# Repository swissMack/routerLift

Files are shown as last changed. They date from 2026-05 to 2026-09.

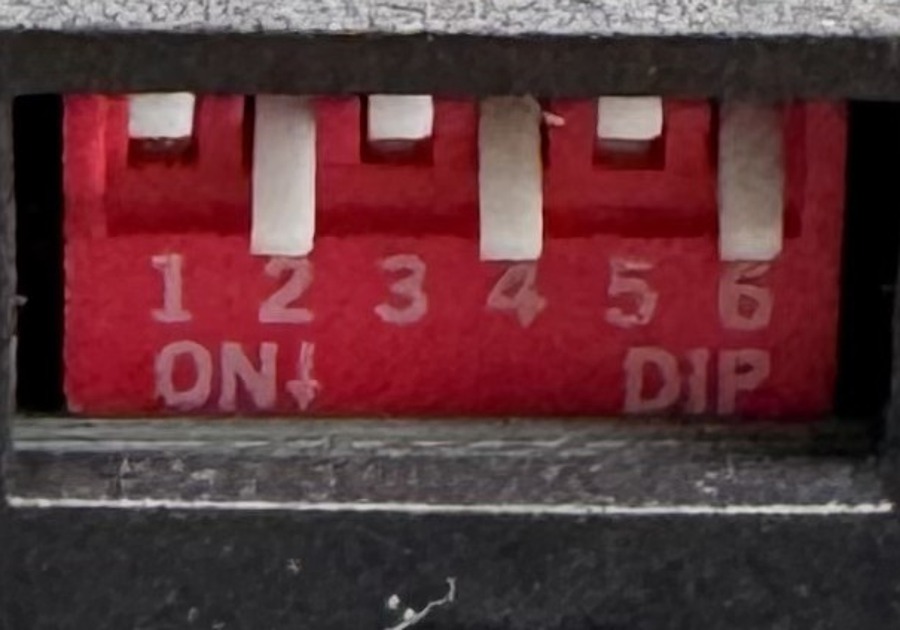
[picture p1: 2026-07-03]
docs/dip_zoom.jpg

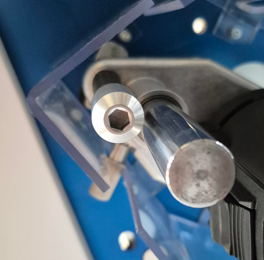
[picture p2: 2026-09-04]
docs/reference/sauter-fml-p-lower-hex.png

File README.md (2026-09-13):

# routerLift

Open-firmware automated router lift for a workshop router table. A 4.3" touch
panel with a CNC-style handwheel drives a stepper-actuated lift body, with
motion handled by stock [FluidNC](https://github.com/bdring/FluidNC).

Specification: `docs/Router_Lift_Requirement_Specification_RevG.md`, amended by
the Rev H design set.

## Architecture — two boards

Motion and the operator interface run on separate controllers. FluidNC does not
run on the ESP32-S3, and the S3 board cannot carry the machine's full pin
budget, so one board cannot do both.

```
  ESP32-S3 touch panel                 classic ESP32
  ┌──────────────────┐   UART/GRBL   ┌──────────────────┐
  │  hmi/  (our C++) │ ────────────► │ stock FluidNC    │   TB6600 ─► stepper
  │  LVGL, handwheel │ ◄──────────── │ firmware/*.yaml  │   NPN limits, probe
  └──────────────────┘  status @10Hz └──────────────────┘   relay ─► router
```

The HMI polls status with `?` every 100 ms — FluidNC's automatic report only
fires on change. No status for 500 ms counts as link loss: the HMI sends a feed
hold and invalidates Z0.

**The HMI has no motion authority.** Soft limits, hard limits, homing and
probing are all enforced by FluidNC. A bug in our firmware can produce a *wrong
cutting depth*; it must never produce an *unsafe move*. Keeping FluidNC stock
means the safety-critical parts are not ours to get wrong — any proposal that
needs FluidNC source edits forfeits that.

| Directory | Contents |
| --- | --- |
| `firmware/` | FluidNC machine definition — `config.yaml` only, **no source** |
| `hmi/` | PlatformIO ESP32-S3 project: LVGL UI, handwheel, buttons, GRBL sender |
| `legacy/` | The retired v1.x single-ESP32 firmware. Reference only, not built |
| `docs/` | Spec, Rev H design set, wiring, protocol, bench tests, mechanics |

## Hardware

**Motion board** — classic ESP32 (30-pin USB-C ESP32-WROOM-32 devkit) running
unmodified FluidNC v4.1.0. TB6600 driver at 1/8 microstepping (1600 pulse/rev),
24–36 V, common anode +3.3 V, 1.0–1.4 A/phase. NPN NC inductive limit switches,
`G38.2` probe for tool zeroing, `Relay` spindle output for router power with a
2500 ms spin-up gate. Host lift: sauter FML-P (1.5 mm lead, 65 mm travel).

**Operator panel** — Guition JC4827W543C board (XH-S3E N4R8 module: ESP32-S3,
4 MB flash, 8 MB octal PSRAM). 4.3" 480×272 IPS NV3041A panel over QSPI via
Arduino_GFX, GT911 capacitive touch, LVGL 8.4. The board brings only ten GPIOs
out to connectors, so the panel buttons and the rough/fine selector sit on an
MCP23017 on its own I²C bus (GPIO 15/16) — the touch bus is not brought out.
MPG handwheel decoded on the S3's PCNT peripheral (GPIO 6/7), through a 74LVC14
on 3.3 V (two stages per channel, non-inverting).

STOP is deliberately *not* on the panel: it is wired to FluidNC's own
`feed_hold_pin`, so it halts motion even if the HMI has crashed.

Full pin map and wiring: `docs/HARDWARE.md`, `docs/WIRING-RevH.svg`,
`docs/SCHEMATIC-RevH.svg`, `docs/PINOUT.svg`.

## Status

Bench truth lives in `docs/BRINGUP-LOG.md`. As of 2026-09-13:

| Half | State |
| --- | --- |
| Motion board | ✅ FluidNC v4.1.0 flashed, `config.yaml` parses, bare-board acceptance passed (limits NC-correct). Five items still to verify — `firmware/README.md` |
| Screen board | ✅ Display and touch working on the JC4827W543C |
| UART link (Step B) | ✅ Link up, link-loss feed hold + Z0 invalidation, recovery verified |
| `hmi/` increments 1–3 | Built. Display, touch and link bench-verified; MPG and buttons **not yet wired** (waiting on the level shifters) |
| `hmi/` increment 4 | Cycles (standard → bit-change → dovetail → keyhole). Not started |
| `hmi/` increment 5 | Fault log, diagnostics, runtime hours. Not started |
| Mechanics | Lift body (sauter FML-P) **not yet bought**. See `docs/MECHANICS-RevH.md` |

HMI flash use is ~24% of the 3 MB app slot.

### Nothing has been cut yet

Two numbers come from the sauter FML-P datasheet, not a measurement, and both
follow from its 1.5 mm screw lead:

- `firmware/config.yaml` → `steps_per_mm: 1066.67` (1600 pulse/rev ÷ 1.5 mm),
  with `max_travel_mm: 65`
- `hmi/include/config.h` → `MpgCfg::SCREW_LEAD_MM = 1.5`

**Until `steps_per_mm` is measured against a dial indicator, every depth this
machine cuts is wrong by an unknown factor** — and wrong invisibly, because
there is no stall detection to contradict a bad number. The commissioning
procedure is in `firmware/README.md`.

One design question is also open: the foot switch needs both press and release
edges for dead-man behaviour, and FluidNC's `macro0_pin` may only fire on
assert. The proposed split (press on FluidNC, release mirrored to an HMI
expander input) is written up in `firmware/README.md` and not yet verified.

## Build

Only the HMI is built from this repo. FluidNC is flashed from its own release.

```sh
git clone git@github.com:swissMack/routerLift.git
cd routerLift
pio run -e hmi           # compile
pio run -e hmi -t upload # flash the S3 panel
pio run -e hmi-diag      # bring-up diagnostics build (no I2C, display logging)
pio device monitor       # serial console at 115200
```

Libraries resolve on first build: ESP32Encoder, GFX Library for Arduino, LVGL
8.4, TAMC_GT911. If upload cannot connect because the app has hung, hold BOOT,
tap RST and retry.

For the motion board, flash stock FluidNC from installer.fluidnc.com, upload
`firmware/config.yaml` with `$Xmodem/Receive=/localfs/config.yaml`, and restart
with `$Bye` — see `firmware/README.md`. Its console is also reachable over WiFi:
`telnet routerlift.local 23`.

## Documentation

| File | Contents |
| --- | --- |
| [docs/Router_Lift_Requirement_Specification_RevG.md](docs/Router_Lift_Requirement_Specification_RevG.md) | The requirement spec |
| [docs/DESIGN-PLAN-RevH.md](docs/DESIGN-PLAN-RevH.md) | The RevG pivot, phase by phase |
| [docs/UART-PROTOCOL.md](docs/UART-PROTOCOL.md) | HMI ↔ FluidNC command vocabulary |
| [docs/MECHANICS-RevH.md](docs/MECHANICS-RevH.md) | Lift body selection and stepper drive design |
| [docs/LIFT-COMPARISON.md](docs/LIFT-COMPARISON.md) | The four candidate lift bodies, compared |
| [docs/BOM.md](docs/BOM.md) | Bill of materials |
| [docs/HARDWARE.md](docs/HARDWARE.md) | Pin map and wiring detail |
| [docs/BENCH-TEST.md](docs/BENCH-TEST.md) | Staged bring-up — each step passes before the next part is fitted |
| [docs/BRINGUP-LOG.md](docs/BRINGUP-LOG.md) | What has actually been proven on the bench, session by session |
| [docs/UX.md](docs/UX.md) | Interaction model |
| [docs/DESIGN-QA.md](docs/DESIGN-QA.md) | The design Q&A that settled the constants |
| [hmi/README.md](hmi/README.md) | HMI modules, build gotchas, Z0 validity rules |
| [firmware/README.md](firmware/README.md) | FluidNC setup, pre-power-up checks, commissioning |
| [CHANGELOG.md](CHANGELOG.md) | Version history |
| [CONTRIBUTING.md](CONTRIBUTING.md) | Code style, commit conventions |

`docs/SUPERSEDED.md` lists the drawings the Rev H set replaced.
`docs/reference/FXBB-original/` holds the FXBB FräsLift V3 documentation this
project draws on.

## Safety

This machine drives a high-RPM router. Read `firmware/README.md` before first
power-up — five of its checks are destructive or silently wrong if got wrong,
including PSU voltage (48 V destroys the TB6600), TB6600 common anode at 3.3 V
not 5 V, and NPN-not-PNP limit sensors.

Z0 — the reference every cut depth is measured from — is owned entirely by the
HMI, and **there is no override anywhere** on probe validity. That is
deliberate: a wrong reference does not fail visibly, it produces a
plausible-looking cut at the wrong depth. See `hmi/README.md`.

The author accepts no liability for misuse. Test with the router unpowered
first.

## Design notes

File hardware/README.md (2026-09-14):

# Hardware — KiCad schematics (Rev H)

Generated from Python. **Do not edit the `.kicad_sch` files in KiCad** — the next
regeneration overwrites them. Change `tools/*.py` and run:

    hardware/tools/verify.sh     # tests, generate, ERC, PDFs, pin cross-check

After running `verify.sh`, restore unchanged PDFs with `git checkout -- hardware/*/*.pdf` unless the schematics actually changed.

| Project | What | For layout? |
| --- | --- | --- |
| `motion-carrier/` | ESP32 devkit sockets, 5 input conditioners, field terminals, link header | Yes |
| `panel-carrier/` | 74LVC14 MPG shifter, MCP23017 + pull-ups, MX1.25 leads to the display | Yes |
| `system/` | Mains, E-stop, PSU, modules and cabling between them | No — reference |

`tools/check_pins.py` fails if a schematic pin disagrees with `firmware/config.yaml` or
`hmi/include/pins.h`.

## PCBs

Boards are generated once, then **the routed `.kicad_pcb` is the source** — edit it in KiCad's PCB
Editor freely. Rebuilding from scratch overwrites hand edits:

    hardware/tools/get_freerouting.sh                                   # once
    /Applications/KiCad/KiCad.app/Contents/Frameworks/Python.framework/Versions/Current/bin/python3 \
      hardware/tools/gen_pcb.py motion-carrier                          # or panel-carrier

`get_freerouting.sh` fetches v2.1.0, which runs on Java 21. `gen_pcb.py` uses only the jar for
that pinned version (`hardware/tools/.cache/freerouting-2.1.0.jar`) and stops with an error if it
is missing. To try another version, delete the cached jar first, then run e.g.
`FREEROUTING_VERSION=v2.4.1 hardware/tools/get_freerouting.sh` — and run `gen_pcb.py` with the same
`FREEROUTING_VERSION` set. v2.2 and later need Java 25.

**Regenerating a board is destructive.** It overwrites the `.kicad_pcb`, replaces the `board` and
`net_settings` sections of its `.kicad_pro` (design rules and net classes edited in the GUI are
discarded; other sections are kept), and rewrites the fab zip, the board PDF and the renders.

`verify.sh` and `gen_pcb.py` run DRC with schematic parity and `--severity-all`, so warnings fail
too. Autorouting gives a different result each run, so check DRC after every regeneration.
Fabrication zips for JLCPCB (2-layer, 1.6 mm, HASL) are in `<board>/fab/<board>-jlcpcb.zip`.

| Board | Size | Mounting |
| --- | --- | --- |
| motion carrier | 140 × 80 mm | 4× M3 for standard DIN-rail PCB clips |
| panel carrier | 80 × 62 mm | 4× M3 corners, standoffs |

Mounting hole centres, in mm from the board's top-left corner (x right, y down). Each board's holes
form a rectangle:

| Board | Holes (x, y) | Pitch (x × y) |
| --- | --- | --- |
| motion carrier | (4, 4), (93, 4), (4, 56.5), (93, 56.5) | 89 × 52.5 mm |
| panel carrier | (4, 4), (76, 4), (4, 58), (76, 58) | 72 × 54 mm |

## Open items shown on the drawings

- Contactor coil voltage (BOM block A).
- MPG output type — R3/R4 on the panel carrier are DNP until known.
- Foot-switch release mirror (MCP GPA6) — needs a second pedal contact or a shared-contact decision.
- ESP32 devkit row spacing assumed 25.4 mm — measure before ordering boards.
- DIN-rail clip hole spacing — check against the clips bought.

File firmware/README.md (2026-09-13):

# Motion controller — stock FluidNC

This directory contains **no source code**. The motion controller runs an unmodified FluidNC
binary; `config.yaml` is the entire machine definition.

That is deliberate and worth protecting. Homing, soft limits, hard limits, probing and step
generation are the safety-critical parts of this machine, and keeping FluidNC stock means they
are not ours to get wrong. Any proposal that requires editing FluidNC's source forfeits this.

---

## Flashing and configuration

1. Flash stock FluidNC to the ESP32 (**classic ESP32, not S3** — FluidNC does not run on the S3).
   Easiest: **installer.fluidnc.com** in Chrome or Edge (Web Serial), WiFi build.
2. Upload `config.yaml` to the board's filesystem — from the installer's file browser / terminal
   (`$Xmodem/Receive=/localfs/config.yaml`, confirm the `Received N bytes` count matches the local
   file), or via the FluidNC web UI — `routerlift.local` once it has joined WiFi, or
   `192.168.0.1` on the `FluidNC` fallback access point.
3. `$Config/Filename=config.yaml` if it is not the default.
4. **Restart with `$Bye`** — `$CD` shows the config loaded at the last boot, not the file on disk.
5. Read the boot log from the first line. Any `[MSG:ERR:` line, or `Board None` with a
   1000 mm Z axis, means the YAML did not parse and FluidNC fell back to defaults — the safe
   non-configured state. `$CD` dumps what was actually loaded.

**YAML parser gotchas (FluidNC v4.1.0):**
- The spindle section key is `Relay:` — `relay_spindle:` is silently ignored.
- Never put a comment on a section-header line, and never use `'` or `"` inside comments. An
  apostrophe in a comment on `Relay:` broke parsing of the whole file.

Flashed: **FluidNC v4.1.0 (esp32-wifi)**, 2026-09-13, on a 30-pin USB-C ESP32-WROOM-32 devkit
(CH340, 4 MB flash).

### Bare-board acceptance (passed 2026-09-13)

Board on USB only, nothing else connected:

| Check | Expected |
| --- | --- |
| Boot log | `Machine routerLift`, `Board ESP32 devkit v1`, no `ERR` lines |
| Z axis | `Axis Z (-0.001,65.001)`, `stepstick Step:gpio.26 Dir:gpio.27 Disable:gpio.14` |
| Relay | `Relay Spindle Ena:NO_PIN Out:gpio.4` |
| HMI link | `UART1 Tx:gpio.17 Rx:gpio.16 … Baud:115200`, report interval 100 |
| Limits, unwired | `ALARM: Hard Limit` and `Pn:Z` — correct, NC wiring reads open as tripped |
| Limits, D33 + D25 jumpered to GND | `?` shows no `Pn:Z`; after `$Bye` only `ALARM:14` (Unhomed, from `must_home`) |

`E (…) esp_core_dump_flash: No core dump partition found!` appears on every boot. It is harmless
— FluidNC's partition table has no core-dump area.

### Console and network

- **WiFi:** joins the home network as `routerlift.local` (192.168.1.82 on the bench); if it
  cannot, it falls back to access point `FluidNC` with the default password `12345678` — change
  it before commissioning, or `$WiFi/Mode=Off`.
- **Telnet console, port 23:** `telnet routerlift.local 23` gives the same `?`, `$` commands and
  messages as the USB serial port. Use it when USB serial does not enumerate (e.g. a charge-only
  cable), or while the HMI is on UART1.
- **`$Limits`** shows the live state of every input pin, per pin. Exit with **`!`** — any other
  key leaves it running. A limit that reads active with the switch closed is usually a bad
  jumper or terminal, not the GPIO.

---

## ⚠ Before first power-up

Five things that are destructive or silently wrong if got wrong. All are in
`docs/WIRING-RevH.svg` too.

| # | Check |
| --- | --- |
| 1 | **PSU is 24–36 V.** A 48 V supply destroys the TB6600 instantly (abs max ≈40–42 V) |
| 2 | **TB6600 common anode is +3.3 V, not +5 V.** At 5 V the input opto never fully turns off → missed steps at rapid → silent depth error under DEV-01 |
| 3 | **Limit sensors are NPN, never PNP.** A PNP sensor sources 24 V into the GPIO. `LJ12A3-4-Z/BY` = NPN NC; any `/A…` suffix is PNP |
| 4 | **Switches wired NC**, so a broken wire faults the machine rather than silently disabling the limit |
| 5 | **Two red buttons, two meanings.** The E-stop mushroom kills mains; STOP is a flush feed-hold button. Mount them apart |

---

## ⚠ Unresolved: the foot switch needs both edges

**This is the one genuine problem found while writing the config, and it is not yet solved.**

The agreed behaviour (Q39) is **hold to plunge, release to retract** — dead-man, so stepping off
returns the cutter. That needs two events: press *and* release.

FluidNC's `macro0_pin` fires a macro when the pin is **asserted**. Whether it does anything on
release is unverified, and if it does not, a macro pin alone cannot implement dead-man behaviour.

There is a second problem even for the press half. A macro is a fixed G-code string, but the
plunge target is a per-job value that lives in the HMI. FluidNC cannot know it.

### The plan, pending verification

**Press half.** The HMI rewrites the macro whenever the target depth changes:

```
$Macro0=G90 G21 G1 Z<target> F120
```

The foot switch then plunges **locally on the motion board**, with no link involvement and no
latency — which is exactly why the switch belongs on this board.

**Release half.** Wire the same foot-switch contact to a **spare MCP23017 input on the HMI**
(A6 — ten I/O are free). The HMI sees the release edge and sends the park move. One switch, two
readers, no ambiguity about which owns the plunge.

### Consequences to accept or reject at review

- If the link is dead, the plunge still works but the automatic retract does not. Link loss
  already triggers a feed hold, so the cutter stops — but it stops **at depth**, not retracted.
- That is weaker dead-man behaviour than a single-board design gives. It is a direct cost of the
  split architecture and should be judged deliberately, not discovered on the bench.

### Alternatives if verification rules the mirrored approach out

1. Move the foot switch entirely to the HMI expander — both edges are then trivial, but every
   plunge crosses the link and gains latency.
2. Change the semantics to press-down / press-up toggle — solvable with one edge, but it is a
   mode, and losing track of it means the cutter stays up when you think it is down. Q39
   deliberately rejected this.

---

## Items to verify against the installed release

Everything in `config.yaml` marked ⚠, plus these. All are from working knowledge of FluidNC
rather than from the docs of the specific build in hand.

| # | Item | Why it matters |
| --- | --- | --- |
| 1 | ✅ `uart1:` / `uart_channel1:` key names — **verified v4.1.0** | Without a second channel the HMI shares the USB port and the debug console is lost |
| 2 | ✅ `report_interval_ms` exists — **verified v4.1.0**, but it only reports **on change**, not as a heartbeat. Resolved: the HMI polls `?` every 100 ms and treats 500 ms of silence as link loss (Step B, 2026-09-13) | An idle machine in Alarm sends nothing, so without polling the HMI shows NO LINK |
| 3 | Soft-limit envelope sign convention | We home negative and work positive — the less common orientation. Prove with `$J=` at both ends |
| 4 | `macro0_pin` edge behaviour | Decides the foot-switch question above |
| 5 | Macro length limits, and whether `$Macro0` can be rewritten over the wire | The press-half plan depends on it |
| 6 | Homing pull-off failure raises a distinct alarm code | So the HMI can say "stuck switch", not just "limit" |
| 7 | `Relay:` spindle reports non-zero `S` in status (the section key is `Relay:`, verified v4.1.0) | The ROUTER LED depends on reading it |

---

## Commissioning: measuring `steps_per_mm`

**`steps_per_mm: 1066.67` in `config.yaml` is derived, not measured.** It comes from the sauter
FML-P's published 1.5 mm lead and the TB6600 at 1600 pulse/rev (1600 / 1.5). Confirm it on the
real lift before trusting any depth.

1. Fit a dial indicator (0.01 mm) against the carriage.
2. `$J=G91 G21 Z10 F300` and note indicated travel — or command a known number of motor
   revolutions, which is more precise.
3. `steps_per_mm = 1600 / (mm travelled per motor revolution)`
4. Update `config.yaml`, re-upload, and repeat to confirm.
5. Record the measured value and date here: `__________`

Until this is done, every depth this machine cuts is wrong by an unknown factor — and wrong in a
way nothing detects, because DEV-01 leaves no stall sensing to contradict a bad number.

---

## Settled values and where they came from

| Setting | Value | Decided in |
| --- | --- | --- |
| `steps_per_mm` | **1066.67 — derived from FML-P spec, not yet measured** | `docs/MECHANICS-RevH.md` |
| `max_rate_mm_per_min` | 720 (12 mm/s) | Q14 |
| `acceleration_mm_per_sec2` | 100 | Q16 |
| `max_travel_mm` | 65 — FML-P published travel, not yet measured | MEC-01 |
| Lead / microstepping → steps | 1.5 mm lead, 1600 pulse/rev → 1066.67 steps/mm | `docs/MECHANICS-RevH.md` |
| TB6600 current | 1.0–1.4 A/phase, common anode +3.3 V | `docs/BOM.md` |
| `idle_ms` | 255, never disable | Q17 |
| Homing seek / feed | 600 / 60 mm/min | Q14–16 |
| `pulloff_mm` | 2.0 mechanical, ~3.0 inductive | Q12 |
| Positive direction | Bit rising, home at bottom | Q19 |
| Microstepping | 1/8, 1600 pulse/rev | Q18 |
| `spinup_ms` | 2500 | SAF-03 gate |
| `must_home` | true, no exceptions | Q11 |

Plunge feed (2 mm/s, 120 mm/min) is not in this file — it is a `G1 F` value the HMI sends per
move, since it varies by cycle.

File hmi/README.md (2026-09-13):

# HMI — ESP32-S3 operator panel

Our firmware. Runs on the Guition JC4827W543C (XH-S3E N4R8 module: ESP32-S3, 4 MB flash, 8 MB
octal PSRAM) and acts as a **GRBL sender** to the FluidNC board over UART.

```sh
pio run -e hmi          # build
pio run -e hmi -t upload
pio run -e hmi-diag     # board bring-up diagnostics
pio device monitor
```

Upload goes over the S3's native USB (`/dev/cu.usbmodem*`) and auto-resets. Only if the app has
hung: hold **BOOT**, tap **RST**, then upload.

`hmi-diag` skips all I²C (touch and MCP23017), waits for USB, logs display bring-up and cycles
red/green/blue. Never leave it on a panel in service — it has no touch or buttons.

## Pins (all in `include/pins.h`)

| Function | GPIO | Connector |
| --- | --- | --- |
| UART to FluidNC | TX 18 → FluidNC 16, RX 17 ← FluidNC 17 | P4 (P5 is the same — use one) |
| MPG A / B | 6 / 7, via a **74LVC14 on 3.3 V**, two stages per channel | P3 |
| MCP23017 (I²C bus 1, 100 kHz) | SDA 15 / SCL 16, external 4.7 kΩ pull-ups to 3.3 V | P3 |
| GT911 touch (I²C bus 0, on-board only) | SDA 8 / SCL 4, INT 3, RST 38 | — |
| NV3041A QSPI panel | CS 45, SCK 47, D0–D3 21/48/40/39, backlight 1 | — |
| Spares | 5, 9, 14 — **avoid 46** (boot strap) | P2 |

The MPG shifter is non-inverting, so `MpgCfg::SIGNALS_INVERTED = false`. A 74HCT14 is the wrong
part: it needs a 5 V supply and would drive 5 V into the S3.

## Restoring the factory demo

The board's original firmware is backed up in full (4 MB) at
`~/Documents/routerLift-firmware-backups/screen-original-dashboard.bin`. Restore with:

```sh
esptool.py --chip esp32s3 write_flash 0 screen-original-dashboard.bin
```

## Architecture invariant

**This board has no motion authority (ELE-11).** Soft limits, hard limits, homing and probing are
enforced by FluidNC. Nothing here may enforce a limit or be the last line of defence. A bug in
this firmware can produce a *wrong cutting depth*; it must never produce an *unsafe move*.

`Link` is the single chokepoint — nothing else may write to the UART. That is what keeps the
command vocabulary in `docs/UART-PROTOCOL.md` §4 exhaustive rather than aspirational.

**Status polling.** `Link` sends the `?` realtime byte every 100 ms (`LinkCfg::POLL_MS`).
FluidNC's `report_interval_ms` only reports on change, so without polling an idle machine sends
nothing and the link reads as lost. No status for 500 ms (`LinkCfg::TIMEOUT_MS`) = link lost:
feed hold is sent and Z0 is invalidated. Z0 stays invalid after the link recovers.

## Increments

| # | Scope | State |
| --- | --- | --- |
| 1 | Link, handwheel, buttons, headless serial diagnostics | Built. Link ✅ bench-verified (Step B); handwheel and buttons **not yet wired** |
| 2 | Display: Arduino_GFX NV3041A QSPI panel + GT911 touch + LVGL + main screen | Built. ✅ Display and touch bench-verified |
| 3 | Z0 validity, two-touch probe sequencing, named presets in NVS | Built. Z0 invalidation on link loss ✅ verified; probe not yet tested |
| 4 | Cycles: standard → bit-change → dovetail → keyhole | Not started |
| 5 | Fault log, diagnostics screen, runtime hours | Not started |

Increment 3 is enough, once the MPG, buttons and probe are wired, to attempt bench-test steps 1,
2, 4, 5 and the probe half of 7: the panel renders and touch tracks, the link comes up and status
is parsed, one detent moves the axis exactly 0.01 / 0.10 mm, the buttons and rough/fine selector
read correctly, and a two-touch probe sets Z0 while a failed probe leaves it invalid. Bench
progress is logged in `docs/BRINGUP-LOG.md`.

Flash ~24% of the 3 MB app slot (`huge_app.csv`).

## Modules

| File | Responsibility |
| --- | --- |
| `Link.{h,cpp}` | GRBL sender. Status parsing, one-command-in-flight window, realtime bytes |
| `Wheel.{h,cpp}` | MPG decode via PCNT, coalescing, look-ahead clamp, cancel-on-reversal |
| `Buttons.{h,cpp}` | MCP23017 polling, debounce, short/long press, ROUTER LED |
| `Display.{h,cpp}` | NV3041A QSPI panel, GT911 touch, LVGL plumbing, backlight dimming |
| `Ui.{h,cpp}` | LVGL screens. Increment 3 still builds the main screen only |
| `Zero.{h,cpp}` | Two-touch probe sequencing and Z0 validity - the most safety-relevant logic here |
| `Store.{h,cpp}` | NVS: named presets, plate thickness, teachable ceiling |
| `../include/lv_conf.h` | LVGL config - minimal, `lv_conf_internal.h` defaults the rest |
| `main.cpp` | Bring-up and the loop |
| `../include/pins.h` | **The only place GPIO numbers appear** |
| `../include/config.h` | Tunable constants, each citing the Q&A item that decided it |

## Two values from the datasheet, not a measurement

Both follow from the sauter FML-P's published 1.5 mm screw lead. The lift body is not yet bought,
so neither has been measured.

| Where | Value | Why provisional |
| --- | --- | --- |
| `firmware/config.yaml` | `steps_per_mm: 1066.67` | 1600 pulse/rev ÷ 1.5 mm — derived, confirm with a dial indicator |
| `include/config.h` | `MpgCfg::SCREW_LEAD_MM = 1.5` | Same lead; sets the look-ahead clamp distance |

Too large a clamp and it does nothing; too small and the wheel feels like it is dragging.

## Build notes worth keeping

- **`src_dir` / `include_dir` must be in `[platformio]`, not `[env:]`.** PlatformIO silently
  warns and then fails with "Nothing to build".
- **Do not name a constant `LINE_MAX`.** POSIX `<limits.h>` defines it as a macro and the
  collision produces a baffling "expected ']' before numeric constant" in an unrelated header.
- **The stock `esp32-s3-devkitc-1` definition assumes 8 MB flash and no PSRAM.** This board is
  4 MB flash with 8 MB *octal* PSRAM, so `board_build.arduino.memory_type = qio_opi` and the
  flash size overrides are both required. Octal is confirmed on the bench: with `qio_qspi` the
  PSRAM ID read fails.
- **Partitions must be `huge_app.csv`.** The stock table is the 8 MB layout and boot-loops on
  this 4 MB flash.
- **LVGL needs `-DLV_CONF_INCLUDE_SIMPLE` and `-I hmi/include` in `build_flags`.** Without them
  it looks for `../../lv_conf.h` next to the library and the entire of LVGL fails to compile,
  with an error that points at LVGL's internals rather than at your configuration.
- **Arduino-ESP32 core 3.x dropped the channel-based LEDC API.** `ledcSetup` + `ledcAttachPin`
  become `ledcAttach(pin, freq, res)` and `ledcWrite(pin, duty)`. Note an old 2.x header may
  still be on disk and will mislead you if you grep for the signature.
- **Arduino_GFX colour constants are `RGB565_BLACK`, not `BLACK`,** in 1.6.x.

## The panel constructor

The board is a **Guition JC4827W543C**: NV3041A over 4-bit QSPI (`Arduino_ESP32QSPI` +
`Arduino_NV3041A`), pins from the Guition vendor example, all in `pins.h`. The constructor's
`ips = true` is required — without it every colour comes out inverted. The GT911's axes are both
mirrored against the panel at rotation 0, so `Display.cpp` flips them.

**Wrong-board symptom worth remembering:** Rev H targeted a Sunton ESP32-4827S043 RGB panel.
That firmware boots cleanly on this board and shows nothing — `gfx->begin()` on an RGB bus cannot
tell no panel is attached. The gitignored `docs/4.3inch_ESP32-4827S043.zip` is that other board's
vendor pack and is not a reference for this one.

## Z0 validity — the rules

Z0 is the reference every cut depth is measured from, and **FluidNC has no concept of it**. This
board owns it entirely, which makes the FW-09 invalidation rules the most safety-relevant logic
in the HMI.

Invalidated by: link loss, alarm, bit-change entry, a failed probe, and never-set at boot.
Homing loss and E-stop arrive as an alarm and are covered by that.

**There is no override anywhere.** Not on the probe self-check, not on the re-probe after a bit
change, not on preset recall with an invalid Z0. That is deliberate: with no stall detection
(DEV-01), a wrong reference does not fail visibly — it produces a plausible-looking cut at the
wrong depth. Every override is a place to trust a number the machine cannot verify.

Two paths deliberately kept separate:

- `start()` runs the two-touch probe. The slow second touch is what delivers MOT-06's ±0.02 mm;
  the fast first touch only finds roughly where the surface is.
- `setHereUnprobed()` is the ZERO long-press. Never routed through the probe path, so it cannot
  be mistaken for a measured touch-off.

FLT-02's probe self-check is enforced by FluidNC via `probe: check_mode_start`, not here. If the
probe is already triggered — a trapped croc clip, a chip bridging the plate — `G38.2` returns an
error rather than instantly "succeeding" and setting Z0 wherever the bit happens to be.

## Next: increment 4

The cycles, in the order set by Q37: standard → bit-change → dovetail → keyhole. Keyhole last —
it is the only cycle where the cutter moves under power while engaged.

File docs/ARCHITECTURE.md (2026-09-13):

# Architecture

> **SUPERSEDED — this describes the single-board v1 design** (one ESP32 doing motion and UI, ILI9488 TFT,
> `MotorControl`, MCP23017 board-ID, DM542). It is kept for provenance and as a porting reference for
> `legacy/`. **Do not build from it.** The current Rev H split architecture (stock FluidNC + ESP32-S3 HMI
> over UART) is described in `docs/DESIGN-PLAN-RevH.md`, `docs/REVIEW-RevH.md` and
> `docs/ARCHITECTURE-DIAGRAM.svg`. See `docs/SUPERSEDED.md`.

## Module map

```
main.cpp ──┬── Safety       (fault state, hardware watchdog)
           ├── IOExpander   (MCP23017 abstraction)
           │     ├── Endstops, brass stamp, foot switch
           │     ├── Function board ID (4 bits)
           │     └── Rate switch (3 positions)
           ├── MotorControl (FastAccelStepper wrapper, mm-based, soft limits)
           ├── MPG          (manual pulse generator, velocity scaling)
           ├── RateSwitch   (x1 / x10 / x100 hardware switch)
           ├── Touch        (XPT2046 + rectangle hit-testing)
           ├── Homing       (two-stage seek)
           ├── Zeroing      (brass-stamp tool-length sensor)
           ├── Presets      (NVS, 6 slots)
           ├── Relay        (SSR + startup delay)
           ├── FootSwitch   (debounced via MCP23017)
           ├── FunctionBoard (boot-time board identity)
           ├── Menu         (touch-driven screen state machine)
           └── Display      (TFT_eSPI sprite, 8-bit colour)
```

## State machine

Top-level `AppState` in `main.cpp`:

```
BOOT ─→ HOMING ─→ IDLE
                   │
                   ├─→ PLUNGE       (foot switch pressed, relay ready)
                   ├─→ ZEROING      (brass-stamp routine running)
                   └─→ FAULT        (any module reported a fault)

PLUNGE      ─→ RETURN_PARK (foot switch released)
RETURN_PARK ─→ IDLE        (motor reached park)
ZEROING     ─→ IDLE        (zeroing complete or failed)
FAULT       ─→ IDLE        (user acknowledged)
```

Sub-state machines live inside `Homing` and `Zeroing`, each running a
two-stage seek (fast then slow re-approach for accuracy).

## Safety architecture

Three independent barriers, all converging on `Safety::trigger()`:

1. **Soft limits in `MotorControl::moveToMm()`.** Every motion request
   passes through this single function, which rejects out-of-range targets
   before they reach the stepper driver. No caller can bypass it.
2. **Endstop polling in `main::checkEndstops()`.** Outside of Homing and
   Zeroing (which expect endstop triggers), any endstop activation is a
   fault. The fault handler immediately calls `Motor.emergencyStop()` and
   `Relay.turnOff()`.
3. **Hardware watchdog (`esp_task_wdt`).** A 5-second window. If
   `Guard.update()` doesn't kick the watchdog (because the main loop is
   stuck), the ESP32 reboots cleanly with the relay defaulting to OFF.

All three converge on `SafetyMon::trigger()` which:
- Sets the global fault code (first fault wins, no override)
- Calls `Motor.emergencyStop()` (immediate halt + driver disable)
- Calls `Relay.turnOff()` (router power off)
- Forces the UI into `FAULT_VIEW` until the user acknowledges

## Input model

| Input | Used for | Notes |
| --- | --- | --- |
| MPG (rotary) | Jogging on main, value editing in calibration | 100 PPR full-quad |
| Rate switch | Selects MPG step band (x1/x10/x100) | Hardware, polled |
| Touch panel | All menu navigation, button taps | XPT2046, polled |
| Foot switch | Plunge to target / return to park | MCP-routed, debounced |
| Endstops | Homing trigger + safety | Active-LOW NPN |
| Brass stamp | Tool zeroing trigger | Active-LOW NPN |
| Board ID jumpers | Boot-time function board detection | 4 bits |

The MPG never opens a menu and the touch panel never jogs the lift.
This separation is deliberate: it means accidental touch can't change
the cutting position, and accidental MPG rotation can't accidentally
trigger a menu action.

## Step-size computation

```
effective_step_mm = RateSwitch.baseStepMm() * velocity_scale

where:
  RateSwitch.baseStepMm():
    x1   → 0.001 mm
    x10  → 0.010 mm
    x100 → 0.100 mm

  velocity_scale ∈ [1.0, 10.0], a smoothed function of MPG pulses/second:
    pps ≤  5  → 1.0
    pps ≥ 80  → 10.0
    in between → linear interpolation
```

At full sprint with `x100`, you get 1.0 mm per pulse — 10 mm per full
wheel turn. At dead slow on `x1`, you get 1 µm per pulse for fine
tuning. The result feels like a Bridgeport handwheel with a multiplier.

## Display rendering

Each frame is drawn to a `TFT_eSprite` (8-bit colour) and pushed in one
SPI burst. This gives flicker-free updates at 20 Hz with plenty of CPU
left for everything else.

Touch coordinates are mapped from the XPT2046's 12-bit ADC space to the
480×320 pixel coordinate system using calibration constants in
`Touch.cpp` — adjust these if hit points are off-target on your panel.

## Why this architecture

The system has three categories of work, each with different timing
requirements:

| Work | Latency need | Owner |
| --- | --- | --- |
| Step generation | Microseconds | FastAccelStepper (hardware timer) |
| Counting MPG pulses | None — hardware | ESP32 PCNT peripheral |
| Servicing UI, sensors, state machine | ~50 ms | Main loop |

Keeping these layered means the main loop can be unhurried (and easy to
read) without compromising motion smoothness or losing pulses. The
modules above the main loop are deliberately stateless about timing —
they expose request/query APIs that the loop polls at its own rate.

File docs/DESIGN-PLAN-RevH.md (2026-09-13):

# Pivot routerLift to the RevG split architecture

## Context

`docs/Router_Lift_Requirement_Specification_RevG.md` (committed as `d8e507a`) closes the
controller-platform open item with a **split architecture**: FluidNC on a standard ESP32 for
motion, and a 4.3" ESP32-S3 touch board as the operator panel over UART. FluidNC does not run
on the ESP32-S3, and the S3 board cannot carry the machine's full pin budget — hence two boards.

The repo currently holds a **bespoke single-ESP32 Arduino firmware** (29 files in `src/`,
`include/config.h`, `platformio.ini`) built around an ILI9488 TFT and an MCP23017 expander.
RevG supersedes that design wholesale. This plan retires it to `legacy/` and builds the two
new halves.

Decisions taken with the user this session (these are settled — do not relitigate):

| Decision | Choice |
|---|---|
| Old firmware | Move to `legacy/`, keep in tree as porting reference, not built |
| Display board | **Guition JC4827W543C** (NV3041A QSPI) — confirmed at bench bring-up 2026-09-13 |
| I/O split | Operator inputs on the S3; every safety-relevant input stays on FluidNC |
| UART protocol | GRBL/gcode — S3 acts as a GRBL sender, FluidNC stays stock |
| Soft limits | **Commissioning-only** in `config.yaml` — no longer operator-editable (see below) |
| Scope | Full pivot, both halves |

The board matches spec Annex B.10, which records a JC4827W543C with an NV3041A QSPI panel. This
plan originally claimed the board in hand was an ESP32-4827S043 RGB parallel variant and that B.10
was wrong; bench bring-up on 2026-09-13 proved that claim mistaken. **B.10's board record stands.**
The I/O split does depart from B.10's "HMI only" rationale and needs ELE-11 reworded.

## Target layout

```
routerLift/
  firmware/          FluidNC config.yaml + macros + notes (no C++ — stock FluidNC binary)
  hmi/               PlatformIO ESP32-S3 project: LVGL UI + operator inputs + GRBL sender
  legacy/            the v1.x bespoke firmware, unbuilt, for reference
  docs/
```

---

## Phase 1 — Repo restructure

1. `git tag -a v1.1.0-bespoke -m "Final bespoke single-ESP32 firmware before RevG pivot"`
   so the working tree is recoverable by tag as well as by path.
2. `git mv src legacy/src`, `git mv include legacy/include`, `git mv platformio.ini legacy/platformio.ini`.
3. Add `legacy/README.md`: one paragraph stating this is the pre-RevG design, that it is not
   built by CI, and a table mapping each old module to where its logic now lives (below).
4. New root `platformio.ini` with a single `[env:hmi]` pointing at `hmi/`. `legacy/` is excluded
   from the build by simply not having an env.

**Where the old modules go** — this table belongs in `legacy/README.md`:

| Legacy module | Destination |
|---|---|
| `MotorControl`, `Homing`, `Safety` (limits/faults) | FluidNC `config.yaml` — native axes, homing, soft limits |
| `Zeroing` (brass stamp) | FluidNC probe (`G38.2`) driven by HMI |
| `Relay` | FluidNC `Relay` spindle (`M3`/`M5`) |
| `FootSwitch` | FluidNC `macro0_pin` + `$Macro0` |
| `RateSwitch` | HMI — rough/fine selector per ELE-09 (2 positions, not the old 3-band x1/x10/x100) |
| `MPG` | HMI — ESP32-S3 PCNT quadrature |
| `Menu`, `Display`, `Touch` | HMI — LVGL screens |
| `Presets`, `Settings` | HMI — NVS on the S3. **Except `softMinMm`/`softMaxMm`**, which become commissioning-only `config.yaml` values; their calibration rows are not ported |
| `IOExpander` | HMI — MCP23017 at 0x20 on the S3's own I²C bus 1 (GPIO 15/16) for the five panel buttons, rough/fine and the ROUTER LED. Port the polling and debounce |
| `FunctionBoard` | **Dropped.** The board-ID jumper logic has no equivalent |

---

## Phase 2 — `firmware/config.yaml` (FluidNC)  ✅ WRITTEN, bare-board verified 2026-09-13 (steps_per_mm derived, not measured)

Stock FluidNC binary; all machine definition is config. Pin numbers come from
`docs/superseded-wiring_diagram.svg` (Annex B.9), with MPG A/B (GPIO 34/35) now freed because the handwheel
moved to the S3.

| Signal | GPIO | Notes |
|---|---|---|
| STEP → TB6600 PUL− | 26 | common-anode: PUL+/DIR+/ENA+ to **+3.3 V**, ESP32 sinks (see below) |
| DIR → TB6600 DIR− | 27 | |
| **`ENA` → TB6600 ENA−** | **14** | **Added — diagram marks ENA± n/c. See below** |
| Router contactor | 4 | as the `Relay` spindle so `M3`/`M5` owns router power |
| Probe (touch-off plate) | 32 | |
| Home / bottom limit | 33 | machine zero per MOT-04 |
| Top limit | 25 | bounds bit-change rapid per MOT-05 |
| Foot switch | 13 | `macro0_pin`; **use 13, not 34/35** — GPIO 34–39 have no internal pullups |
| UART1 TX → S3 | 17 | |
| UART1 RX ← S3 | 16 | |
| **`DRIVER_ALARM`** | **35** | **Reserved for MOT-10 / DEV-01 closure — see below.** Wire NC through the limit conditioning circuit |
| Reserved | 34 | Held for feedback hardware; do not reassign |
| **STOP button** | **21** | `feed_hold_pin` — native FluidNC control pin. **Works with no HMI involvement**, so it halts motion even if the S3 has crashed or the UART dropped. This is why it does not live on the HMI expander with the other five buttons |

### Level shifting — required in exactly one place

| Signal | Level | Shifter? |
|---|---|---|
| MPG A/B → S3 GPIO 6/7 | **5 V** | **Yes, required** — ESP32-S3 is not 5 V tolerant |
| STEP/DIR/ENA → TB6600 | 3.3 V sinking | No — *provided* the common anode change below |
| Limits (mechanical or NPN) | contact / open collector to 3.3 V | No — conditioning circuit covers it |
| Probe, foot switch, selector, cycle start | dry contact to GND | No |
| UART, HMI ↔ FluidNC | 3.3 V both ends | No (B.10) |
| Relay module input | 3.3 V into a 5 V board | Usually fine — **verify at bench test 3** |

**Change the TB6600 common anode from +5 V to +3.3 V.** `docs/superseded-wiring_diagram.svg` currently says
"common +5 V". With common-anode wiring the ESP32 sinks `PUL−`/`DIR−`, and in the *off* state
drives the pin to 3.3 V — leaving 5 − 3.3 = 1.7 V across the input optocoupler, above its ~1.2 V
LED forward drop. The opto never cleanly turns off. This is the classic ESP32↔TB6600 failure and
presents as **missed steps at higher step rates** — which on this build means silent depth error,
because DEV-01 leaves nothing to detect it. Tying the common to +3.3 V gives a true 0 V off state
and ≈8 mA on state ((3.3 − 1.2)/270 Ω), at the low end of the input range but generally sufficient.
Fallback if bench test 3 shows missed steps at rapid: a 74HCT245 buffer driving the inputs at 5 V.

**MPG conditioning.** A resistor divider is adequate on rate grounds — 100 PPR at a fast hand spin
is well under 1 kHz against ELE-10's 5 kHz ceiling. Given the router alongside, prefer a
**74LVC14 on 3.3 V with two inverter stages per channel** for Schmitt hysteresis against EMI.
Its inputs are 5 V-tolerant and its outputs swing to 3.3 V. *Design correction 2026-09-13:* this
previously said 74HCT14, which needs a 5 V supply and would then drive 5 V into the S3 (and is
out of spec at 3.3 V). If a 74HCT14 has already been bought, do not connect its outputs.

⚠️ **`MPG::SIGNALS_INVERTED` flips to `false`.** The legacy constant is `true`, assuming PC817
optocouplers. A divider, a 74LVC245, and a two-stage 74LVC14 are all **non-inverting**. Getting
this wrong makes the handwheel count backwards.

### TB6600 `ENA` — wire it, do not leave n/c

The diagram marks `ENA±` not connected, which means the motor is energised continuously (at the
RevG diagram's 2.8 A/phase; Rev H sets the TB6600 to 1.0–1.4 A/phase) with no idle-current reduction. Two costs: FluidNC cannot de-energise the motor at
all, and ENV-03's 8-hour session requirement comes under real thermal pressure in both motor and
driver. The legacy firmware *had* software disable (`Pins::ENABLE`, used by `Safety::trigger()`);
that capability is lost in the new wiring because GPIO 27 became DIR.

Leaving it n/c is defensible — MEC-02's self-locking ACME screw holds position unpowered, so
nothing drops. But wire `ENA−` to **GPIO 14** anyway: it costs one pin, enables FluidNC's
`disable_pin` and `$Stepper/IdleTime`, and can be left permanently enabled by default. Discovering
you want it later means re-opening the enclosure.

### Closed-loop feedback (MOT-10) and closing DEV-01

MOT-10 makes feedback optional and §14 leaves "closed-loop in the first build?" open, but DEV-01
is only closable by a stall-capable driver *or* an encoder. Three paths, and they are not equal:

| Path | Mechanism | FluidNC impact | Pins |
|---|---|---|---|
| **A — TMC5160** | StallGuard load sensing; driver reports impending stall | Native — FluidNC drives Trinamic over SPI/UART and can home on StallGuard | SPI/UART bus |
| **B — Closed-loop driver** (CL57T, iHSS, integrated NEMA 23) | Encoder on the motor, driver closes the loop internally, asserts **ALARM** on lost position | **One digital input.** Stock FluidNC, still step/dir | 1 |
| **C — Raw encoder into the ESP32** | A/B quadrature into FluidNC for position verification | ✗ **Not supported** — FluidNC has no closed-loop feedback for step/dir axes | 2–3 |

**Path C is the trap**, and it is what "add an encoder" naturally suggests. Implementing it means
forking FluidNC, which destroys the "stock FluidNC, `config.yaml` only" property this whole
architecture rests on. Verify against the installed release, but plan as if unavailable.

**Path A also closes the ELE-01 deviation** ("Trinamic-class driver"), so it settles both halves
of DEV-01 in one move. **Path B is the cheap retrofit** — keeps the TB6600 wiring model, needs one
input, works with stock FluidNC today.

**Action now, cost one wire:** reserve **GPIO 35 as `DRIVER_ALARM`**, wired NC through the same
conditioning circuit as the limits so that both a driver fault and a broken wire fault the
machine. DEV-01 then closes as a `config.yaml` edit rather than a rewire. The pins freed by moving
the MPG to the S3 (34/35) are exactly what feedback hardware wants — reserve them, do not reuse.

Key values (as written in `firmware/config.yaml`):

- `steps_per_mm: 1066.67` — TB6600 at 1/8 microstepping = 1600 pulses/rev over the sauter FML-P's
  published 1.5 mm lead. **Derived from the datasheet, not measured** — confirm with a dial
  indicator. (Earlier drafts used 800 from an assumed T8 2 mm lead; the legacy firmware used
  1000 steps/rev at 4 mm pitch. Both are superseded.)
- `max_travel_mm: 65` — the FML-P's travel, short of MEC-01's ≥75 mm (open Rev H item). Soft
  limits enabled (MOT-09).
- Rapid ≥10 mm/s, plunge 1–5 mm/s default 2–3 (MOT-08).
- Two-stage homing (fast seek, back off, slow confirm) to satisfy MOT-06's ±0.02 mm.

### Endstop management

Three independent layers, deliberately owned by three different things. Nothing in the HMI
appears in any of them — this is the core of ELE-11.

| Layer | Mechanism | Owner |
|---|---|---|
| **E-stop** | NC contact breaking mains L, feeding both the PSU and the router contactor | Hardware only. Not a GPIO, not visible to firmware (SAF-01) |
| **Hard limits** | `limit_neg_pin: gpio.33` (bottom), `limit_pos_pin: gpio.25` (top) | FluidNC — alarm state, motion halted |
| **Soft limits** | `$Limits/Soft`, envelope from `mpos_mm` + `max_travel_mm: 65` | FluidNC (MOT-09) |

**Three tiers of limit, and they must not be conflated:**

| Tier | Set by | Where | Changes |
|---|---|---|---|
| Hard limits | Physical switch position | Bolted to the machine | Never |
| Soft limits | Commissioning — travel + home reference | `config.yaml` | Once, at build |
| Job ceilings | Operator — presets, teachable Target Set (Phase 4b #2) | HMI, NVS | Every job |

**Soft limits move from tier 3 to tier 2 — a deliberate, user-approved change.**
`legacy/src/Settings.cpp` persists `softMinMm`/`softMaxMm` to NVS and `legacy/src/Menu.cpp`
exposes them as editable calibration rows. **Do not port those rows.** The operator must not be
able to widen their own envelope from the panel, and keeping them would give the HMI write access
to a safety-relevant setting, against ELE-11. The affordance is *replaced*, not removed: per-job
ceilings come from presets and the teachable Target Set, both of which can only ever be
*narrower* than the commissioned envelope. The HMI displays the envelope; it never writes it.

**Why the hard limits carry more weight on this build than on a typical machine.** DEV-01 means
the TB6600 has no stall detection, so FLT-01 is unimplementable here. Open-loop with no stall
sensing lets position error accumulate *silently* — a step missed during a heavy plunge does not
announce itself, it quietly shifts everything after it. Soft limits cannot catch this, because
FluidNC trusts its own step count. **The bottom switch is the only thing that ever discovers the
drift.** Two consequences: the switches are a primary protection here rather than a backstop, and
FW-09's Z0-invalidation discipline must be strict, because a limit hit tells you something
slipped but never how much.

**This deletes code rather than porting it.** `legacy/src/Homing.cpp`'s four-state
SEEK_FAST→BACKOFF→SEEK_SLOW→DONE machine and `main::checkEndstops()`'s polling — including its
careful suppression of endstop faults while homing or zeroing is active — are both native FluidNC
behaviour. The `homing:` block (`seek_rate`, `feed_rate`, `pulloff_mm`, `settle_ms`) does the
two-stage approach that MOT-06's ±0.02 mm needs, and FluidNC already knows a limit hit during a
homing cycle is expected rather than a fault. Do not reimplement any of it.

**The bottom switch does double duty** — home reference *and* negative hard limit on one pin.
MOT-04 makes it machine zero. FluidNC supports this directly; the top switch is limit-only and
exists to bound the bit-change rapid (MOT-05).

**Switch selection — decided. Support BOTH mechanical and inductive, selectable by config.**
Two switches fitted: bottom (GPIO 33, home + negative limit) and top (GPIO 25, positive limit).
The user has ordered both types; the design must accept either without rework.

**Both wired NC, and both then present identically to the ESP32:**

| | Idle (not at limit) | At limit | Wire break |
|---|---|---|---|
| Mechanical NC, COM→GND | contact closed → LOW | opens → pull-up → HIGH | floats → HIGH = triggered ✓ |
| Inductive NPN NC | transistor conducting → LOW | turns off → pull-up → HIGH | floats → HIGH = triggered ✓ |

Both are **active-HIGH with a pull-up**, and both fail safe — for the inductive sensor a severed
*supply* wire also reads as triggered. So the FluidNC pin string is the same either way:
`limit_neg_pin: gpio.33:pu` (active high is the default — no `:low`). This is the opposite
polarity from the usual CNC convention, a deliberate consequence of choosing NC for fail-safe.

**One common input-conditioning circuit accepts either type** — this is what makes swapping a
config change rather than a rewire, and it satisfies ELE-04 in hardware:

```
sensor out ──┬── 10k ──┬── GPIO 33
             │         │
          4k7 to 3V3   ├── BAT54S clamp to 3V3 / GND
                       └── 100nF to GND
```

The 4k7 pull-up sits on the **sensor side** of the 10 k series resistor, as drawn. On the GPIO
side, a closed switch would only pull the pin down to ~2.2 V (a 4k7/10k divider) and never read LOW.

- 10 k series + clamp means an accidental 24 V on the line delivers ~2 mA into the clamp instead
  of destroying the ESP32 — a live risk now that both sensor types share a drawer.
- 10 k × 100 nF ≈ 1 ms RC filter — ELE-04's "debounced, EMI-hardened" met in hardware, not
  software. Covers mechanical contact bounce (1–5 ms) too.
- External 4k7 pull-up rather than the internal ~45 k, keeping rise time sub-millisecond.

**Verify the inductive part numbers before wiring.** On the common `LJ12A3-4-Z/xx` family:
**`/BY` = NPN NC — required.** `/BX` = NPN NO, `/AY` = PNP NC, `/AX` = PNP NO. **Any `/A` suffix
is PNP and sources 24 V into the GPIO.** The clamp circuit survives it; a bare pin does not.

**Mechanical option:** roller-lever microswitch, NC, dry contact to GND. Omron **SS-5GL2** or
equivalent; V-156-1C25 for a more robust body; Honeywell 914CE / Omron D4C for IP67 per MEC-06.
Buy four — two fitted, two spares. **Roller lever chosen for overtravel, not repeatability:** with
no stall detection (DEV-01) a runaway drives into the switch until the controller reacts, and a
plain plunger bottoms out in ~0.5–1 mm and is destroyed where a lever deflects through several mm.

**Home-switch repeatability is not depth-critical**, for either type. FW-01 references cut depth
to the probe Z0, not to the home switch, so home variation shifts the soft-limit envelope and does
*not* move cut depth. This is why the inductive option's weaker repeatability (1–3 % of sensing
distance, ~0.04–0.12 mm, temperature-dependent) is acceptable here despite looking marginal
against MOT-02.

**Per-type config profiles.** Keep two commented blocks in `config.yaml` — the pin strings are
identical, only these differ:

| Setting | Mechanical | Inductive |
|---|---|---|
| `pulloff_mm` | 2 | 3 — larger release hysteresis |
| homing `feed_rate` | 60 mm/min | 40 mm/min — weaker repeatability, approach slower |
| Harness | 2-wire shielded pair | 3-wire + 24 V supply |

Wire **COM + NC**, leave NO unconnected. Shielded twisted pair, shield grounded at the controller
end only, routed away from the motor cable.

**Fit a hard mechanical stop just beyond each switch** — a shoulder or bolt head the carriage
cannot pass. The switch tells the controller to stop; the stop guarantees it. Cheap redundancy
given DEV-01, and it means an overrun damages nothing.

Other switchgear to purchase: 1 foot switch (momentary NO, GPIO 13), 1 rough/fine selector (SPDT,
MCP23017 A5), 1 cycle-start button (momentary, MCP23017 A0), and 1 E-stop — **latching
mushroom-head, NC, mains-rated**, since SAF-01 has it breaking L to both the PSU and the router
contactor. Not a logic-level button.

Three things to settle before wiring, in priority order:

1. **Confirm the ordered inductive sensors are NPN NC** (see part-number suffixes above) before
   anything is powered. `docs/superseded-wiring_diagram.svg` says only "shielded twisted pair · debounced
   (ELE-04)" and never states the type; the pre-RevG `CLAUDE.md` assumed NPN with a 24 V common.
   Record the actual as-built type and the conditioning circuit in Rev H rather than inheriting.
2. **Wire NC, not NO.** A broken wire or pulled connector then reads as triggered and faults the
   machine, rather than silently disabling the limit. FXBB made polarity an operator menu item
   (menu 13–15); for us it is a `config.yaml` pin modifier, which is correct — a commissioning
   decision, not an operating one.
3. **GPIO 33 and 25 both have usable internal pullups**, though the external 4k7 is preferred for
   rise time. This is not incidental: GPIO 34–39 have *no* internal pullups, which is exactly why
   the foot switch moved to GPIO 13 and the freed 34/35 stay unused. Do not quietly reassign a
   limit onto 34–39 later.
4. **Verify the soft-limit envelope convention.** FluidNC derives the travel envelope from
   `mpos_mm` together with `max_travel_mm` and the homing direction, and the sign convention
   differs between homing toward positive and toward negative. We home *down* to machine zero and
   work upward (positive = bit rising into the cut), which is the less common orientation. Confirm
   against the installed release's docs and prove it with `$J=` moves at both ends before trusting it.

**Two failure modes to design against, not just the trigger case:**

- **Stuck-on switch** — the FXBB diagnostic is worth stealing: if the axis has retreated ~4 mm and
  the switch still reads triggered, that is a dead switch or inverted polarity, not a limit
  (`ino:427-435`). FluidNC raises a pull-off failure alarm for the same condition; confirm it
  surfaces distinctly enough for the HMI to name the cause, and add an HMI-side check if not.
- **Phantom triggers from router EMI** — the real-world risk for a machine sitting next to a
  universal-motor router. ELE-04 mandates hardened inputs and ACC-07 is a 5-minute run with zero
  phantom triggers. FluidNC's software debounce alone is not the answer: shielded twisted pair
  (already on the diagram), an RC filter at the controller end, limit wiring routed away from the
  motor cable, and shield grounded at one end only.

Config areas checked against the installed FluidNC v4.1.0 at bench bring-up (2026-09-13):

- **Second UART channel — ✅ verified.** `uart1:` plus `uart_channel1:` load as written, and this is
  what makes "stock FluidNC, config only" possible. **`report_interval_ms` exists but reports only
  on change** — an idle machine sends nothing, so it is not a heartbeat. The HMI therefore **polls
  `?` every 100 ms** and treats 500 ms without a status report as link loss (see
  `docs/UART-PROTOCOL.md` §3 and §7.2).
- **Spindle key — ✅** it is `Relay:`, not `relay_spindle:` (the old key is silently ignored).
- **YAML parser —** rejects comments and quotes on section-header lines.
- **Console —** `$Limits` shows per-pin state and is exited with `!`; the console is also
  reachable over WiFi telnet at `routerlift.local:23`.
- **`$Macro0`** for the foot-switch plunge cycle — **still unverified**: whether `macro0_pin`
  acts on the release edge (dead-man retract), macro length limits, rewriting `$Macro0` over the
  wire, and whether it can be made conditional on spindle-ready (SAF-03 / the legacy
  `Relay.isReady()` gate). If it cannot, the readiness gate moves into the HMI and the macro stays
  a bare move.
- Also still unverified: the homing pull-off alarm code, the soft-limit sign convention (item 4
  above), and whether the `Relay` spindle reports non-zero `S`.

Also write `firmware/README.md`: which FluidNC release, how to flash it, how to upload
`config.yaml`, and the `$` settings that are not in the YAML.

---

## Phase 3 — `docs/UART-PROTOCOL.md`  ✅ COMPLETE

Written. Closes the §14 open item. GRBL/gcode over UART1, 115200, 3.3 V both sides, no level shifting.
Document, with worked examples:

- **Status:** HMI parses `<Idle|MPos:0.000,0.000,-12.345|FS:0,0>`. State, machine position, and
  feed drive the whole display (ELE-08).
- **Jog:** each MPG detent → `$J=G91 G21 Z<step> F<rate>`. Use jog commands, not `G91 G0`, so
  `0x85` jog-cancel is available and jogs never enter the queued motion buffer.
- **Homing:** `$H`. **Probe:** `G38.2 Z-<max> F<slow>` then read `PRB:` report.
- **Immediate:** `!` feed hold, `~` resume, `0x18` soft reset, `0x85` jog cancel.
- **Router:** `M3`/`M5` via the `Relay` spindle.
- **Framing rules:** line-oriented, `\n`-terminated, one `ok`/`error:N` per line sent; the HMI
  keeps a bounded in-flight window and never sends a new line before the previous `ok`.
- **Link-loss behaviour:** defined and bench-verified. The HMI polls `?` every 100 ms; if no status
  report arrives for 500 ms it sends `!`, shows LINK LOST, inhibits the handwheel, invalidates Z0
  (which stays invalid after recovery until re-probed) and refuses to originate motion. Critically — per ELE-11 — link loss must
  **not** be able to start motion or block a stop, and the E-stop chain is hardware and is
  unaffected either way.
- A short table mapping each §7 canned-cycle step to the exact command sequence.

---

## Phase 4 — `hmi/` (ESP32-S3 firmware)  ◐ increments 1–3 built

Status 2026-09-13: increments 1–3 are built and bench-verified for **display, touch and the UART
link** (including link loss and recovery). Buttons and MPG are coded against the pin map but not
yet wired. Increments 4 (cycles) and 5 (fault log / diagnostics) are not started. HMI flash is
~24 % of the 3 MB app partition.

### Pin map (the tight part)

The JC4827W543C brings only ten GPIOs out to its JST 1.25 mm connectors (P2 46/9/14/5, P3
6/7/15/16, P4 17/18 with GND and 3.3 V; P5 duplicates P4). The QSPI panel, touch bus, octal PSRAM
(33–37) and TF card (10–13) reach no connector. Final budget:

| Function | GPIO | Connector |
|---|---|---|
| UART TX → FluidNC RX(16) | 18 | P4 |
| UART RX ← FluidNC TX(17) | 17 | P4 |
| MPG A / B (**via 74LVC14 level shifter on 3.3 V**) | 6 / 7 | P3 |
| I²C bus 1 SDA / SCL (**MCP23017 only**, external 4.7 kΩ pull-ups) | 15 / 16 | P3 |
| Spare | 5, 9, 14 | P2 |
| Avoid | 46 (boot strap — never drive at power-up) | P2 |

P3 has no power pins; take GND and 3.3 V for the MPG shifter and the expander from P4.

**Panel buttons go on an MCP23017 at 0x20, not on GPIOs.** Five HMI-side buttons plus the
rough/fine switch and LED would use most of the ten connector pins. The expander needs its own
I²C bus because the GT911's bus is not brought out; it costs two GPIOs, drives the ROUTER LED, and
leaves ten I/O spare. Port the polling and
debounce from `legacy/src/IOExpander.cpp`; drop its board-ID logic.

| MCP23017 | Function |
|---|---|
| A0 | CYCLE START — start cycle / advance pass |
| A1 | ROUTER — toggle `M3`/`M5` |
| A2 | BIT CHANGE — short: rapid to top + lock out; long: exit, forcing re-probe |
| A3 | ZERO — short: probe `G38.2`; long: set zero here without probing |
| A4 | PRESET — short: recall active; long: save current height |
| A5 | Rough/fine selector (ELE-09) |
| A6 | Foot switch mirror (display only — the foot switch itself is FluidNC GPIO 13) |
| B0 | ROUTER LED — lit = live, blinking = warming |

**STOP is deliberately NOT here** — it lives on FluidNC GPIO 21 as `feed_hold_pin`, so it halts
motion even if the S3 has crashed or the UART has dropped. See the FluidNC pin table. The other
five buttons all depend on HMI state (NVS presets, Z0 validity, cycle state machines) and cannot
move to FluidNC without forking it.

⚠️ **STOP is a feed hold, not an E-stop.** Keep them physically unmistakable — E-stop as the
mains-rated red mushroom on yellow, STOP as a flush round button, mounted well apart.

Fixed by the board: QSPI panel CS 45, SCK 47, D0–D3 21/48/40/39; backlight 1; GT911 SDA 8 /
SCL 4 / INT 3 / RST 38; native USB 19/20; console 43/44. Put this map in a single `hmi/include/pins.h` and nowhere else.

### Project setup

- `board = esp32-s3-devkitc-1`, `board_build.arduino.memory_type = qio_opi` (octal PSRAM),
  `board_build.partitions = huge_app.csv` (the stock 8 MB table boot-loops on 4 MB flash).
- `lib_deps`: `moononournation/GFX Library for Arduino`, `lvgl@^8.4`, a GT911 driver. Panel init
  follows the Guition vendor example: `Arduino_ESP32QSPI` + `Arduino_NV3041A` (480×272, IPS
  inversion). Both touch axes are mirrored against the panel at rotation 0.
- LVGL draw buffers in PSRAM.

### Modules

- `Link` — GRBL sender: TX queue with the `ok` window, status-report parser, connection state.
  Polls `?` every 100 ms (`LinkCfg::POLL_MS`); link lost after 500 ms silence (`TIMEOUT_MS`).
- `Wheel` — PCNT quadrature on 6/7, 4× decode, 100 PPR. Scale per ELE-09/B.8: fine
  0.01 mm/detent (1 rev = 1 mm), rough 0.1 mm/detent (1 rev = 10 mm). Emits jog commands via `Link`.
  Rate-limit so a fast spin cannot flood the UART.
- `Cycles` — the §7 state machines: standard scribe/rough/finish scheduler (FW-02: equalised
  passes to D−F, finish at D), dovetail, keyhole, bit-change.
- `Zero` — FW-09 Z0-validity tracking. Invalidated by bit-change entry, homing loss, E-stop,
  brownout, stall, watchdog, **and link loss**. Presets lock when Z0 is invalid (FW-08).
- `Store` — NVS presets and calibration. Port the debounced-flush pattern from
  `legacy/src/Settings.cpp` (2 s dirty-flush) — it is sound and directly reusable.
- `Ui` — LVGL screens. `legacy/src/Menu.cpp` (12 screens) and `legacy/src/Display.cpp` are the
  content reference; the layout is redrawn for 480×272 landscape rather than 480×320.

### Safety invariants to carry across

From the old design's rationale, still binding:

- **One chokepoint for motion.** Every motion request goes out through `Link`. Nothing else writes
  to the UART.
- **MPG jogs, touch navigates.** Accidental touch must not move the cutter; accidental wheel spin
  must not fire a menu action.
- **The HMI has no motion authority (ELE-11).** Soft limits, homing, and the probe are enforced by
  FluidNC, not by the HMI. The HMI's own limit checks are advisory UI only — never the last line
  of defence.

---

## Phase 4b — Capability delta vs the FXBB FräsLift V3

Mined from `docs/reference/FXBB-original/FXBB_RouterLift_1-0-0.ino` (1166 lines) and its manual —
the shipping commercial lift this project replaces. RevG is the more capable machine in almost
every respect, so this is a short list of specific operator affordances worth adopting, not an
architectural rethink.

**Where FXBB has nothing and we already win** (no action — recorded so it is not re-litigated):
multi-pass scribe/rough/finish cycles; named presets (FXBB: one volatile, unnamed slot); router
power switching (FXBB has *no* relay or interlock at all — bit changes rely on operator
discipline); probe with plate-thickness handling; MOT-07 approach-from-below (FXBB has no
backlash compensation whatsoever, only a dead `runOut` code path); plural fault codes (FXBB has
exactly one, `ENDSTOP ERR`); Z0-validity tracking; two limit switches rather than a workspace
band inferred downward from one.

**Gaps worth closing:**

| # | FXBB capability | Our status | Adopt as | Where |
|---|---|---|---|---|
| 1 | **One-revolution look-ahead clamp** — jog target clamped to ≤1 motor rev ahead of actual position, so spinning the wheel fast cannot queue a long move (`ino:282-289`) | **Missing, and matters more for us.** Our MPG emits `$J=` per detent over UART; a fast spin can build a jog queue FluidNC will faithfully execute after the wheel stops | Clamp pending jog distance in `Wheel`; use `0x85` jog-cancel on direction reversal. Stronger than the rate-limit already in Phase 4 | HMI `Wheel` |
| 2 | **Target Set — teachable travel ceiling** — move to a height, long-press, that position becomes a hard upper limit you cannot jog past, so you can plunge blind into the work. Long-press again to clear (`ino:222-252`, `ino:307-312`) | **Missing.** We have static soft limits and saved presets, but nothing operator-teachable in one gesture at the machine | Adopt. A temporary ceiling distinct from both soft limits and presets, with a persistent on-screen indicator | HMI `Cycles` + `Ui`; new requirement |
| 3 | **Live derived values while editing** — setup screens show resulting mm-per-handwheel-revolution next to the raw step count (`ino:937`, `ino:960`) | **Missing.** ELE-08 lists what the display must show but not derived feedback during calibration | Adopt. Show mm/rev and mm/detent live in the calibration screens | HMI `Ui` |
| 4 | **Approaching-limit warning** — `WS MAX`/`WS MIN` shown within 10 steps of either limit (`ino:800-809`) | **Missing.** We fault at the limit but give no warning approaching it | Adopt. Proximity indicator in the status bar | HMI `Ui` |
| 5 | **Stuck-switch diagnostic** — if the axis has retreated ~4 mm and the endstop still reads triggered, raise a distinct fault (wrong NO/NC, dead switch) rather than driving on (`ino:427-435`) | **Partially covered.** FluidNC detects homing pull-off failure, but this is a sharper, better-named diagnostic | Confirm FluidNC's pull-off failure surfaces distinctly; if not, add an HMI-side check. Include the FXBB fault table's symptom→cause pairs in our FLT-05 code list | FluidNC + HMI |

**Considered and rejected:** operator-settable NO/NC polarity per switch (FXBB menu items 13–15) —
in our design that is a `config.yaml` pin modifier, correctly a commissioning decision, not an
operator one. Power-on toolchange (FXBB menu 12) — MOT-04 already mandates homing at power-up, so
making it optional would weaken the requirement. Forcing SLOW jog after zeroing (`ino:507-508`) —
FW-06's 0.05 mm sneak-up covers the intent without an unrequested mode change.

**Shared gap, flagged not scheduled:** both FXBB and our RevG are **mm-only**. Neither supports
inch. Worth a deliberate decision rather than an accident, though a metric shop makes it moot.

---

## Phase 5 — Spec amendment (Rev H)

The build has already diverged from RevG in two recorded ways, so the spec needs a revision rather
than silent drift:

- **Annex B.10** — keep the JC4827W543C/NV3041A record (confirmed on the bench 2026-09-13; the
  earlier plan to replace it with an ESP32-4827S043 was mistaken). Add the connector pin budget:
  UART on P4, MPG and the MCP23017's own I²C bus on P3, spares on P2.
- **ELE-11** — reword. The HMI is no longer display-only; it owns the MPG and panel inputs and
  originates jog/cycle commands. Keep the invariant that it has no *authority over safety*:
  limits, homing, probe, and the E-stop chain are unaffected by HMI failure.
- **§2.1 Baseline** and **Annex B.9** — record the final GPIO split across both boards.
- **§14** — close "HMI↔controller UART protocol"; point at `docs/UART-PROTOCOL.md`.
- New **Annex A.7** changelog row, revision history row for H.

Three existing docs describe the retired architecture and must be rewritten or marked superseded:
`docs/ARCHITECTURE.md`, `docs/HARDWARE.md`, `docs/superseded-SCHEMATIC.svg`. `docs/BENCH-TEST.md`'s
9-step ladder is built around the bespoke single-board firmware. `ARCHITECTURE.md`, `UX.md` and
`BENCH-TEST.md` now carry superseded banners (listed in `docs/SUPERSEDED.md`); Rev H bench
progress is recorded in `docs/BRINGUP-LOG.md` against the Verification section below.

Note `DEV-01` is untouched by all of this: the TB6600 still cannot do stall detection, so FLT-01
and the stall portion of ACC-09 stay deferred.

---

## Verification

Incremental, each step gating the next — no router, no bit, until the last steps.

1. **Build.** `pio run -e hmi` compiles. `legacy/` is not built.
2. **Panel bring-up.** ✅ *Display and touch verified 2026-09-13.* Flash the HMI; LVGL widgets render at 480×272 and GT911 touch tracks. This
   is the highest-risk step (panel driver, partitions, PSRAM mode) — if it fails, use the
   `hmi-diag` env and diff against the Guition vendor example before touching anything else.
3. **FluidNC standalone.** ◐ *Bare board verified 2026-09-13: config parses, limit inputs fault
   when open and clear when jumpered, boot ends in `ALARM:14` (unhomed). `$H`, probe and relay not
   yet exercised — no motor or switches fitted.* Upload `config.yaml`, connect over USB, confirm `$$` reads back, `$H`
   homes on the bottom switch, top limit faults, `G38.2` probes, `M3`/`M5` clicks the relay —
   all **with the motor on the bench, not mounted, and the router unplugged**.
3b. **Both sensor types, before anything is mounted.** With the conditioning circuit built, meter
   the GPIO node while triggering each switch type — confirm it swings 0 V ↔ 3.3 V and never
   exceeds 3.3 V with the inductive sensor powered from 24 V. Then home on each type in turn and
   confirm the identical pin string works for both. Finally, **pull the signal wire mid-idle on
   each** and confirm it faults rather than going quiet — that is the fail-safe claim, and it is
   worth proving rather than trusting.
4. **Link.** ✅ *Link up, EN-reset → immediate LINK LOST, auto-recovery with Z0 still invalid —
   verified 2026-09-13 (`docs/BRINGUP-LOG.md`). The MPG half is still to do.* Cross-wire 17/18 ↔ 16/17, confirm the HMI's status bar tracks `MPos` live as the
   axis is jogged from the USB console. Then confirm the reverse: MPG detents move the axis.
5. **Pin-budget check.** Confirm MPG 6/7 and the expander bus on 15/16 read correctly with the
   panel running and touch active.
6. **Link-loss test.** Pull the UART cable mid-jog. Motion must stop or complete safely and must
   never start; the HMI must show disconnected; `$H`/limits must still work from USB.
7. **Cycles dry-run.** Each §7 cycle end-to-end, air-cutting, router unplugged (ACC-05).
8. **Acceptance.** ACC-01 to ACC-04 repeatability with a dial indicator, then ACC-06/07/10/11.
   ACC-09's stall half stays deferred under DEV-01.

Only after all of the above: router plugged in at lowest speed, no bit in the collet, then
production cuts with an E-stop within arm's reach.

## Risks

- **The HMI board's ten connector GPIOs are the main pin constraint.** Three remain spare (5, 9,
  14); GPIO 46 is a boot strap. If more are needed, the MCP23017's ten spare I/O come first.
- ~~FluidNC's second-UART key names must be verified~~ — verified on v4.1.0 (2026-09-13).
  Remaining FluidNC unknowns: the foot-switch release edge, `$Macro0` rewrite over the wire, the
  homing pull-off alarm code and the soft-limit sign convention.
- The canned cycles and Z0-validity logic living in the HMI is a real consequence of the GRBL
  choice. It is acceptable because FluidNC independently enforces limits, homing, and probing —
  but it means an HMI bug can produce a *wrong depth*, just never an *unsafe move*.

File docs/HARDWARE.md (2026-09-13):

# Hardware

> ⚠️ **Superseded — pre-Rev-H single-board (v1) design.** This page describes the original
> one-ESP32 build (ILI9488, DM542, MCP23017 board-ID, ball screw). The current hardware is the
> Rev H split design: stock FluidNC on a classic ESP32 plus a Guition JC4827W543C ESP32-S3 panel
> over UART. Use `docs/BOM.md`, `docs/WIRING-RevH.md`, `docs/SCHEMATIC-RevH.svg`,
> `docs/PINOUT.svg` and `docs/BRINGUP-LOG.md` instead. The body below is kept for reference only.

## Bill of materials

| Item | Notes |
| --- | --- |
| ESP32 DevKit V1 (WROOM-32) | Any ESP32 board with the listed GPIOs broken out |
| 3.5" ILI9488 SPI TFT, 480×320, with XPT2046 touch | Most commonly sold combined |
| 5 V 4-terminal MPG, 100 PPR | A, B, +V, GND |
| 3-position rotary switch (x1 / x10 / x100) | SP3T, one common + three throws |
| MCP23017 I/O expander | I²C addr 0x20 |
| DM542 stepper driver | Set microsteps to give 1000 steps/rev (or update config) |
| NEMA 23 stepper motor | 1.8°/step native |
| Ball-screw spindle, 4 mm lead | Match `DEFAULT_SPINDLE_PITCH_MM` |
| 698 RS bearing | Between motor shaft and ball screw — eliminates axial play |
| 2× NPN inductive sensors (top + bottom endstops) | Active-LOW; 24 V common |
| 1× NPN inductive sensor (brass-stamp pickup) | Same family as endstops |
| Solid-state relay | Rated for your router's continuous current |
| Foot switch | Momentary, normally open |
| 24 V PSU + 5 V / 3.3 V regulators | Stepper / sensors on 24 V; logic on regulated rails |
| 2× PC817 opto-isolators OR 1× 74HCT14 hex Schmitt inverter | MPG signal level shifting |

## Pin map (ESP32 → external)

| Function | GPIO | Notes |
| --- | --- | --- |
| Stepper STEP | 25 | to DM542 PUL+ |
| Stepper DIR | 26 | to DM542 DIR+ |
| Stepper ENABLE | 27 | to DM542 ENA+ (active-LOW) |
| MPG A | 32 | via opto/HCT, 3.3 V output |
| MPG B | 33 | via opto/HCT, 3.3 V output |
| Router relay (SSR) | 16 | drives SSR control input |
| I²C SDA | 21 | to MCP23017 + future devices |
| I²C SCL | 22 | to MCP23017 + future devices |
| TFT SCK | 18 | shared SPI bus |
| TFT MOSI | 23 | shared SPI bus |
| TFT MISO | 19 | shared SPI bus |
| TFT CS | 15 | dedicated |
| TFT DC | 2 | dedicated |
| TFT RST | 4 | dedicated |
| TOUCH CS | 5 | dedicated, shares SCK/MOSI/MISO with TFT |
| TOUCH IRQ | 17 | optional; polled in v1, hooked for v2 |

## MCP23017 pin map

| Function | Port.Pin | Wiring |
| --- | --- | --- |
| Endstop bottom | A.0 | NPN sensor open-collector to GND (sensor +V from 24 V; signal to MCP via 10 kΩ pull-down to 3.3 V or interface optocoupler) |
| Endstop top | A.1 | same |
| Brass-stamp pickup | A.2 | same |
| Foot switch | A.3 | momentary to GND |
| Board ID bit 0 | B.0 | jumper to GND on function board |
| Board ID bit 1 | B.1 | jumper to GND on function board |
| Board ID bit 2 | B.2 | jumper to GND on function board |
| Board ID bit 3 | B.3 | jumper to GND on function board |
| Rate switch x1 | B.4 | switch common to GND, throw to B.4 |
| Rate switch x10 | B.5 | throw to B.5 |
| Rate switch x100 | B.6 | throw to B.6 |

## MPG level-shifter circuits

The ESP32 GPIO pins are 3.3 V and **not 5 V tolerant**. The 5 V signals from
the MPG must be level-shifted before reaching GPIO 32/33. Two recommended
approaches:

### Option A — PC817 opto-isolation (recommended for workshop noise)

```
  MPG +V (5 V) ─┬─[330 Ω]─┐
                │         │
                │      ┌──┴─── PC817 LED anode
   MPG A ───────┴──────┤
                       └──── PC817 LED cathode → GND
                       
                        ┌─── ESP32 3.3 V
                        │
                       [10 kΩ]
                        │
   PC817 collector ─────┼─── ESP32 GPIO32
                        │
   PC817 emitter ───────┴─── GND
```

One opto per channel (A and B). Signal is inverted — set
`MPG::SIGNALS_INVERTED = true` in `config.h`.

Galvanically isolates the ESP32 ground from the stepper/MPG ground.
Recommended in workshops where the router and stepper introduce ground
bounce.

### Option B — 74HCT14 hex Schmitt inverter (cheap, no isolation)

74HCT family runs on 3.3 V VCC and tolerates 5 V on inputs because of TTL
thresholds. Use two inverters per channel (chain) for a non-inverted output:

```
   ESP32 3.3 V ── HCT14 VCC
   GND          ── HCT14 GND
   MPG A (5 V) ─→ U1A ─→ U1B ─→ ESP32 GPIO32   (double-inverted = pass-through)
   MPG B (5 V) ─→ U1C ─→ U1D ─→ ESP32 GPIO33
```

Set `MPG::SIGNALS_INVERTED = false`. Add 100 nF decoupling on VCC.

### Why not a voltage divider?

Resistor dividers work in theory but the MPG outputs are typically
open-collector at the source, and the ESP32 pin capacitance forms an RC
low-pass with the divider that distorts the quadrature signal at high
spin rates. Use opto or HCT.

## Rate switch wiring

Standard SP3T rotary switch:

```
                ┌── B.4 (x1)
                │
  Common ── GND ┼── B.5 (x10)
                │
                └── B.6 (x100)
```

MCP internal pull-ups idle the lines HIGH. The selected position pulls one
line LOW. `IOExpander::readRateMultiplier()` returns 1, 10, 100, or 0
(invalid).

## Power architecture

```
  24 V PSU ─┬──→ Stepper driver, NPN sensors
            ├──→ Buck → 5 V → MPG, opto LED side, TFT backlight
            └──→ Buck → 3.3 V → ESP32, MCP23017, opto transistor side
```

Keep stepper and logic grounds connected at a single star point near
the PSU to minimise loop area.

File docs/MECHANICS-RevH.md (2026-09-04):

# Mechanics — lift selection and drive design

Document: RTL-MECH-001 · Rev A · 2 September 2026

Records how the lift body was chosen and how the stepper couples to it. **Nothing here is
bought yet**, and two questions are outstanding with the manufacturer.

---

## 1. Where this started

The design assumed a T8 ACME screw with a 2 mm lead, from RevG §2.1 — a description of a machine
that was never built. The mechanics were therefore the critical path and every depth figure in the
project was resting on an invented number.

---

## 2. Rejected — JoinTech SmartLift Digital

A SmartLift Digital was inspected. It is **not a suitable host**, for four reasons:

| Finding | Consequence |
| --- | --- |
| Drive is a **nylon pinion on a large ring gear**, not a lead screw | A stepper does not feel resistance and stop. It would strip the gear |
| That gear is a **known failure point** — an owner stripped it in year two | |
| **JoinTech/iTec is out of business** | No spares. Stripping it scraps the lift |
| Drive input is a **hex socket on the top face** | A motor there sits on the work surface |
| Reported as "never really smooth"; the Wixey DRO lost zeroing within a year | Poor basis for a precision machine |

Source: LumberJocks thread *"Not the router lift to buy"* (2011–2017). One detailed failure report
plus corroboration that spares are unavailable. Not a large sample, but enough — the mechanism
description alone disqualifies it.

**The transferable lesson:** a hand-cranked mechanism is designed around an operator who stops
pushing when something binds. A stepper does not. Any host must survive being driven by something
that cannot feel.

---

## 3. Selected — sauter Fräslift FML-P (pending purchase)

German manufacturer, currently trading, full accessory and spares ecosystem.

| Spec | Value | Consequence |
| --- | --- | --- |
| **Travel per revolution** | **1.5 mm** | `steps_per_mm = 1600 ÷ 1.5 =` **1066.67** |
| Full-step resolution | **0.0075 mm** | **Beats MOT-01's ≤0.01 mm** |
| **Max travel** | **65 mm** | ⚠️ **Below MEC-01's ≥75 mm** — see §6 |
| Height adjustment | 5 mm hex **from above** | Not usable for a motor; see §4 |
| Spindle lock | Knurled clamp **under the table** | Clamps a **guide column**, not the screw |
| Clamping neck | Ø 43 mm | European spindle motors — AMB, Suhner, Mafell |
| Max router | 5 kg, 1,100 W | Sizes the contactor (PWR-03) |
| Insert plate | 306 × 229 × 9 mm, R6 corners | Table cutout |
| Lift weight | 2.9 kg | Carriage ≈ 8 kg with motor |
| Price | €378 new · **€329 B-stock** (`II-SA-FML-P`) | B-stock is the sensible buy for a unit being modified |

**The Ø 43 mm clamping neck is a quiet advantage.** It takes continuous-duty spindle motors with
soft start and electronic speed control — the same motors CNC routers use — rather than a
handheld router with a trigger.

---

## 4. The drive interface

The nominal adjustment is a 5 mm hex through the insert plate from above, which is unusable: a
motor there would sit on the work surface. **But the lower end of the spindle carries its own hex
socket**, visible in the manufacturer's underside photograph.

**Confirmed by Sauter (2026-09-04):** the lift can be driven from the lower hex. Asked directly
whether a motor may drive the screw there, they said yes and sent the photo at
`reference/sauter-fml-p-lower-hex.png` — the screw's lower end passes through an aluminium bearing
block and ends in a hex socket, sitting a few millimetres proud of the block face. So the lower
socket is a manufacturer-sanctioned drive input, not an incidental feature.

What the photo shows and does not show:

| Seen | Consequence |
| --- | --- |
| Hex socket on the screw end, proud of the bearing block | The direct-coupled bracket in this section stands. No dismantling needed |
| A guide column runs right beside the screw end | **Coupling and bracket must clear it** — a jaw coupling for a 6–8 mm bore is Ø 20–25 mm, so the screw-axis-to-column distance decides the coupling. Measure before buying |
| Socket size not measurable from the photo | Visually consistent with the top's SW5; the manual ships one SW5 T-handle driver. **Still measure it** — item 2 below |
| Socket depth unknown | Sets the stub engagement length. A shallow hex under reversing torque wears; use the full depth |

The upper SW5 hex stays reachable through the insert plate. With the motor unpowered the screw is
free to turn (§5.2 says it will not run away), so that hex is a **manual crank for bit changes and
recovery** — cheap insurance against DEV-01. Never crank it against a powered motor.

**The screw rotates in place; the nut travels with the carriage.** Confirmed two ways — the top
hex is operated through the *fixed* insert plate, so the drive end cannot move vertically, and the
underside photograph shows the screw driving the router mount up and down.

That gives the good case: **a rigid bracket below the lift, coupled directly to the lower hex.**
No sliding coupling, no right-angle drive, no dismantling of the mechanism.

The spindle lock clamps a guide column rather than the screw, so it will not foul anything mounted
on the screw end. With a motor fitted it becomes either a redundant control to remove, or a
deliberate bit-change interlock to keep.

### Drive train

| Part | Choice | Reasoning |
| --- | --- | --- |
| Coupling | **Zero-backlash jaw (spider) or Oldham** | Backlash goes straight into MOT-02 repeatability. **No universal joints** |
| Drive stub | Hex bit stock into the coupling bore | ⚠️ **Measure the lower socket** — the 5 mm figure is for the upper one |
| Bracket | Rigid, below the lift, coaxial with the screw | The coupling absorbs residual misalignment; it cannot rescue a bad bracket |

**Speed check:** 12 mm/s ÷ 1.5 mm = 480 rpm = 12,800 steps/s at 1/8 microstepping. Comfortable
for the TB6600 and for FluidNC's step generator.

---

## 5. Two findings that change the electrical design

### 5.1 Turn the driver current down — the motor is dangerously oversized

```
F = 8 kg × 9.81                    = 78.5 N
T = F × lead / (2π × η)              η ≈ 0.25, fine trapezoidal lead
  = 78.5 × 0.0015 / 1.571
  = 0.075 N·m        →  call it 0.15 N·m with allowance
```

The 57HS76 delivers about **2 N·m**. That is better than a **10× margin, and it is a hazard rather
than a comfort**: a motor with far more torque than the mechanism needs, with no stall detection
(DEV-01), will destroy the lift if it ever drives into a hard stop.

**Action: set the TB6600 DIP switches to 1.0–1.4 A/phase, not 2.8 A.** That retains a 5–7× margin
and buys three things — far less destructive potential, much less heat (relevant because
`idle_ms: 255` draws current continuously, against ENV-03), and a quieter machine.

This supersedes Annex B.5's 2.8 A setting, which was chosen when the mechanics were unknown.

### 5.2 It is self-locking — MEC-02 holds

A 1.5 mm lead on a ~12 mm screw gives a lead angle of about **2.3°**, well below the ~5.7°
friction angle for steel on bronze. The carriage will not back-drive unpowered.

Consequence: **`idle_ms: 255` becomes a preference rather than a necessity.** If the motor runs hot
during the ACC-04 ten-minute drift test, switching to a timeout is now safe.

---

## 6. Open items

| # | Item | Why it matters |
| --- | --- | --- |
| 1 | **Permissible spindle torque** — asked of Sauter, still open | Sets the current limit and whether a torque limiter is needed. ⚠️ The manual's "Max. Drehmoment des Fräsmotors: 2 Nm" is the *router motor's* rating, not the lead screw's — it does not answer this |
| 2 | **Lower hex size and depth** — Sauter confirmed adjustment from below (photo in §4); size not yet stated | Sizes the drive stub. Measure across-flats and socket depth on receipt |
| 2a | **Screw-end to guide-column clearance** — new from the photo | Bounds the coupling OD and the bracket footprint |
| 3 | **MEC-01 travel: 65 mm vs the specified ≥75 mm** | Every Sauter model shares 65 mm, so this is not avoidable by model choice. MEC-01 was written for an imaginary machine — the requirement probably needs revising down, but that must be a deliberate decision recorded in Rev H |
| 4 | Motor bracket attachment point | Needs the lift in hand |
| 5 | Endstop mounting and trip flag | Needs the lift in hand |
| 6 | Keep or remove the spindle lock | Redundant control, or bit-change interlock |

---

## 7. Values now carried in the code

All marked provisional until the lift is bought and measured. They now derive from a
**published manufacturer specification** rather than an invention, which is a real improvement —
but a measurement still beats a datasheet.

| Where | Value | Was |
| --- | --- | --- |
| `firmware/config.yaml` `steps_per_mm` | **1066.67** | 800 |
| `firmware/config.yaml` `max_travel_mm` | **65** | 90 |
| `hmi/include/config.h` `SCREW_LEAD_MM` | **1.5** | 2.0 |
| TB6600 DIP current | **1.0–1.4 A** | 2.8 A |

The commissioning measurement in `firmware/README.md` still applies and is still the authority:
wind a known number of motor revolutions against a dial indicator and compute
`steps_per_mm = 1600 ÷ (mm per revolution)`.

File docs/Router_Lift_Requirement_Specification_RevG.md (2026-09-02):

# Requirement Specification

*Stepper-Motor-Driven Router Lift for Repeatable Cut Depths*

Document: RTL-SPEC-001 Revision: G Date: 20 July 2026

Author: Tarik Mackmood Status: Draft for Review

## Revision History

| Rev | Date | Author | Description |
|---|---|---|---|
| A | 9 July 2026  | Tarik Mackmood | Initial draft for review. |
| B | 9 July 2026  | Tarik Mackmood / Claude (review) | Gap-fill and engineering review: new PWR, FLT, ENV, MNT sections; SAF-03/OPS-01 contradiction resolved; MOT-06, ELE-01, FW-09 strengthened; ACC-09–12 added. Full detail in Annex A.1. |
| C | 9 July 2026  | Tarik Mackmood / Claude (review) | As-built motor and driver configuration added (Annex B): 57HS76-3004A08 motor, HLTNC TB6600 driver, wiring map and DIP settings. TB6600 vs ELE-01/FLT-01 recorded as accepted first-build deviation DEV-01. Design baseline supply range constrained for TB6600. Full detail in Annex A.2. |
| D | 19 July 2026 | Tarik Mackmood / Claude (review) | MPG handwheel integrated as the fine-adjustment input (ZS61-type, 100 PPR, 4-wire 5 V): ELE-07 upgraded to Mandatory, new ELE-09 (rough/fine selector and scaling) and ELE-10 (electrical interface), FW-06 updated, new FW-12 (preset trim save-back), Annex B.8 as-built record. DEV-01 unaffected and remains open. Full detail in Annex A.3. |
| E | 19 July 2026 | Tarik Mackmood / Claude (review) | System architecture figure added to §2. As-built data aligned with the bench setup reference: full motor part number HLTNC 57HS76-3004A08-D21-22, TB6600 supply range DC 9–42 V confirmed, ENA terminals left unconnected as-built. Full detail in Annex A.4. |
| F | 19 July 2026 | Tarik Mackmood / Claude (review) | Wiring diagram added as Figure 2 (new Annex B.9): all terminal-level connections including MPG level shifting, TB6600 common-anode signal wiring, motor coil colours, sensor inputs, DC power, and the E-stop/contactor mains chain. Proposed FluidNC GPIO assignments recorded. Full detail in Annex A.5. |
| G | 20 July 2026 | Tarik Mackmood / Claude (review) | Touch HMI integrated: Guition JC4827W543C (ESP32-S3) added as operator display over UART in a split architecture — motion control remains on the FluidNC ESP32 because FluidNC does not run on the ESP32-S3. New ELE-11; Annex B.10 as-built record; Figures 1 and 2 updated; controller-platform open item closed. Full detail in Annex A.6. |

# 1. Introduction

## 1.1 Purpose

This document specifies the requirements for automating the height adjustment of a router mounted in a router table, using a stepper-motor-driven lift. The objective is repeatable, programmable cut depths: multi-pass depth scheduling with a light finishing pass, scribe/scoring passes, joint-fitting to hundredths of a millimetre, and safe canned cycles for dovetail, keyhole, and bit-change operations.

## 1.2 Scope

The specification covers the lift mechanism, motor and drive electronics, position referencing, control firmware, operating modes and canned cycles, safety interlocks, power and electrical installation, fault handling, environmental and maintainability requirements, and acceptance tests. It applies equally to a retrofit of an existing manual lift and a new-build lift. Router selection, table construction, and fence automation are out of scope.

## 1.3 Priority Notation

M = Mandatory (system fails its purpose without it). S = Should have (strongly recommended). C = Could have (optional enhancement).

## 1.4 Definitions

| Term | Definition |
|---|---|
| **Machine zero** | Repeatable lift reference position established by homing against the bottom limit switch. |
| **Z0 (cutting zero)** | Bit-tip reference: the lift height at which the bit tip is flush with the reference surface (table or workpiece top, FW-11), established by touch-off. All cut depths are relative to Z0. |
| **Touch-off** | Procedure that detects contact between the bit tip and a probe plate to establish Z0. Required after every bit change. |
| **Pass** | One feed of the workpiece over the bit at a fixed height. |
| **Roughing increment (R)** | Height increase per roughing pass. |
| **Finish allowance (F)** | Material intentionally left by roughing, removed by the final light pass. |
| **Final depth (D)** | Target cut depth relative to Z0. |
| **Sneak-up mode** | Fine jog mode (0.05 mm increments) used to fit joints to actual stock. |
| **Canned cycle** | Pre-programmed sequence of lift moves and operator prompts. |
| **Stall / missed-step event** | Loss of synchronism between commanded and actual motor position, detected by driver load measurement (e.g., StallGuard) or position feedback. |
| **Probe-plate offset** | Calibrated thickness of the touch-off plate, applied automatically so Z0 refers to the true reference surface (FW-10). |
| **Between-pass repositioning** | A lift move commanded by an active canned cycle between feed passes, initiated only by operator cycle-advance confirmation (OPS-01, SAF-03). |
| **MPG (manual pulse generator)** | A handwheel-operated incremental encoder used as an operator jog input. Each detent commands a configured height increment (ELE-09). An MPG is an input device only — it does not measure carriage or bit position. |
| **HMI (touch display)** | The operator touch screen (ELE-11) that renders status and non-safety soft controls. The HMI has no motion authority; interlocks and Z0 validity are enforced by the motion controller. |

# 2. System Overview

The system raises and lowers the router carriage on a self-locking lead screw driven by a stepper motor under microcontroller control. Repeatability is achieved through discipline, not exotic hardware: a homing switch gives a repeatable machine zero, a touch-off probe re-references the bit tip after every bit change, and every commanded height is approached from below so lead-screw backlash never appears in the cut. Figure 1 shows the complete as-built architecture: operator inputs and sensors feed the controller; the controller commands the drive chain; and the hardware safety chain (E-stop and router contactor) gates power independently of firmware.

Router lift system architecture block diagram

*Figure 1 — Router lift system architecture (as-built, Rev G)*

## 2.1 Design Baseline

The reference architecture assumed throughout this specification:

  - Trapezoidal (ACME) lead screw, T8 profile, 2 mm lead, self-locking, with anti-backlash nut.

  - NEMA 23 stepper motor, ≥ 1.5 N·m holding torque, 200 full steps/rev → 0.01 mm per full step.

  - Trinamic-class driver (TMC2209/5160 or external Leadshine-type), 24–48 V supply. As-built first build: HLTNC TB6600 under deviation DEV-01 — supply shall then be limited to 24–36 V (TB6600 absolute maximum ≈ 40–42 V; a 48 V supply would destroy it). See Annex B.

  - ESP32 or Arduino-class controller running GRBL or FluidNC (homing, soft limits, and probing supplied by the motion firmware). As-built decision (Rev G): split architecture — FluidNC on a standard ESP32 for motion, with a Guition JC4827W543C ESP32-S3 touch display as HMI over UART (ELE-11, Annex B.10). FluidNC does not run on the ESP32-S3, so the display board cannot host the motion firmware.

  - Bottom homing switch, top limit switch, touch-off probe plate, router power relay/contactor.

Alternative components are acceptable provided all requirements below are met. In particular, a ball screw may replace the ACME screw only if a brake or equivalent anti-back-drive measure satisfies MEC-07.

# 3. Mechanical Requirements (MEC)

| ID | Requirement | Priority |
|---|---|---|
| **MEC-01** | Vertical travel shall be at least 75 mm (target 90 mm), sufficient to bury the bit fully below the table and to raise the collet nut fully above the table plate for above-table bit changes. | M |
| **MEC-02** | The drive screw shall be self-locking under router vibration with the motor unpowered (e.g., trapezoidal/ACME T8, 2 mm lead). A ball screw is permitted only with a brake or holding measure meeting MEC-07. | M |
| **MEC-03** | Mechanical backlash shall be minimised with an anti-backlash nut; residual backlash shall be masked by firmware single-direction approach (FW-07). | M |
| **MEC-04** | The lift shall carry the router and carriage (3–6 kg) through full travel and shall deliver sufficient thrust to plunge a keyhole bit into hardwood at 2–3 mm/s (OPS-03). | M |
| **MEC-05** | The carriage shall run on rigid guides (e.g., two hardened rods with linear bearings) with no perceptible play; deflection under normal cutting load shall not measurably alter cut depth. | M |
| **MEC-06** | The screw, guides, and switches shall be protected from chips and fine dust (bellows, wipers, sealed bearings). Control electronics shall be mounted outside the router cabinet (see also ENV-02). | M |
| **MEC-07** | Commanded position shall not drift under sustained router vibration, whether holding via screw self-locking or motor holding current. | M |

# 4. Motion and Positioning Requirements (MOT)

| ID | Requirement | Priority |
|---|---|---|
| **MOT-01** | Positioning resolution shall be ≤ 0.01 mm per full step (achieved by 200 steps/rev with 2 mm screw lead, or equivalent). | M |
| **MOT-02** | Bidirectional repeatability at any commanded height, using the standard from-below approach, shall be within ±0.05 mm; target ±0.02 mm. | M |
| **MOT-03** | Microstepping may be used for smoothness and noise only; positional accuracy shall be based on full steps and shall not rely on microstep linearity. | S |
| **MOT-04** | A bottom limit switch shall provide machine zero. Homing shall be required at power-up before any cycle or preset can execute. | M |
| **MOT-05** | A top limit switch shall bound the bit-change rapid move (OPS-11); approach to it shall use a controlled deceleration, never a mechanical crash stop. | M |
| **MOT-06** | A touch-off probe input (conductive touch plate on the table) shall establish Z0 to within ±0.02 mm as a single-button operation, using a two-touch procedure: a fast find touch followed by a slow confirming touch at reduced feed. Because the lowest point of a fluted bit depends on spindle orientation, the procedure shall either instruct the operator to rotate the spindle so a cutting edge is at bottom dead centre, or support multi-touch averaging across spindle orientations. The probe-plate thickness shall be applied as a calibrated offset (FW-10). | M |
| **MOT-07** | Every final positioning move shall approach the target from below (raising into position) so backlash never appears in cut depth. Overshoot-and-return shall be applied automatically to downward moves. | M |
| **MOT-08** | Rapid traverse shall be at least 10 mm/s; programmed plunge moves shall be rate-controlled and configurable in the range 1–5 mm/s (default 2–3 mm/s). | S |
| **MOT-09** | Soft limits shall prevent commanded motion beyond calibrated travel. | M |
| **MOT-10** | Closed-loop position feedback (encoder-equipped stepper or linear scale/DRO) may be added for verification; the baseline open-loop design with homing and touch-off shall meet MOT-02 without it. | C |

# 5. Electronics and Control Hardware (ELE)

| ID | Requirement | Priority |
|---|---|---|
| **ELE-01** | Stepper driver shall be a TMC2209/5160-class or external industrial driver, powered at 24–48 V DC, sized with ≥ 30% torque margin over the worst-case plunge load. The margin shall be assessed at the maximum commanded speed (MOT-08 rapid) and the selected supply voltage using the motor/driver speed–torque curve — not from holding torque alone, which overstates available torque at speed. Note: the first build deviates from this requirement — see accepted deviation DEV-01, Annex B.7. | M |
| **ELE-02** | The controller shall provide homing, soft limits, and probe (touch-off) support natively, e.g., GRBL or FluidNC on ESP32/Arduino-class hardware. | M |
| **ELE-03** | Operator interface shall provide: jog up/down, selectable increment (including 0.05 mm sneak-up), preset recall, cycle start/advance, and a display of absolute height relative to Z0. Display and soft controls are rendered on the touch HMI (ELE-11); safety-relevant controls remain physical (E-stop per SAF-01; cycle-advance and rough/fine button per ELE-09). | M |
| **ELE-04** | All switch and probe inputs shall be debounced and noise-hardened (shielded cable, twisted pairs, opto-isolation or equivalent) against EMI from the router's universal motor. No phantom triggers shall occur with the router running. | M |
| **ELE-05** | Router mains power shall be switched through a relay/contactor controllable by the lift controller, enabling the hardware interlocks in Section 8 (rating per PWR-03). | M |
| **ELE-06** | Motor holding current shall be configurable; if the screw is fully self-locking, idle current reduction is permitted. | S |
| **ELE-07** | An MPG (manual pulse generator) handwheel shall be provided as the primary fine-adjustment input, in addition to jog buttons. As-built device: ZS61-type 100 PPR handwheel encoder — see Annex B.8. | M |
| **ELE-08** | The display shall show heights in millimetres with 0.01 mm resolution, and shall clearly indicate the Z0-validity state, the active Z0 reference surface (FW-11), the current operating mode, and the active MPG scale (ELE-09). | M |
| **ELE-09** | A rough/fine selector button shall set the MPG scale. Defaults: rough = 0.1 mm per detent (10 mm per handwheel revolution at 100 PPR), fine = 0.01 mm per detent (1 mm per revolution); both values operator-configurable. The active scale shall be indicated on the display (ELE-08). MPG motion shall obey the same interlocks as jog inputs: inhibited while the router is powered (SAF-03) and during any feed pass (OPS-02). When a handwheel adjustment ends with net downward motion, the firmware shall automatically re-approach the final height from below (MOT-07) before the height is used for cutting or saved. | M |
| **ELE-10** | The MPG electrical interface: 5 V single-ended quadrature (A/B), 4-wire (VCC, 0 V, A, B), input frequency capability ≥ 5 kHz with 4× quadrature decoding and glitch filtering. Being single-ended, the MPG cable shall be shielded and routed away from mains and motor wiring per ELE-04; no phantom counts shall occur with the router running (verified in ACC-07). | M |
| **ELE-11** | A touch HMI (as-built: Guition JC4827W543C, Annex B.10) shall render the display functions of ELE-08 and may provide soft controls for non-safety functions (preset selection and naming, pass-list display, configuration, scheduler entry). The HMI connects to the motion controller over UART and shall be non-safety-critical: all motion authority, interlocks, soft limits, and Z0-validity enforcement remain in the motion controller (ELE-02). HMI failure, disconnection, or reboot shall not initiate, sustain, or block the stopping of motion, and cycle-advance shall remain available from a physical control.  | M |

# 6. Firmware — Depth Management (FW)

| ID | Requirement | Priority |
|---|---|---|
| **FW-01** | All cutting heights shall be referenced to Z0 established by touch-off. Machine zero (homing) alone shall not be sufficient to run cutting cycles. | M |
| **FW-02** | A pass scheduler shall accept final depth D, roughing increment limit R, and finish allowance F, and generate: optional scribe pass, equalised roughing passes to depth D − F (each ≤ R), and one finish pass at exactly D. Increments shall be equalised so no undersized final roughing pass occurs. | M |
| **FW-03** | Default roughing limits: R ≤ 3 mm and ≤ half the bit diameter in hardwood; up to bit diameter in softwood/MDF; 1.5–2 mm for large-diameter (panel-raising) bits. Values shall be operator-configurable. | M |
| **FW-04** | Finish allowance F shall be configurable 0.2–0.5 mm (default 0.3 mm). The finish pass exists to remove deflection, burning, and tearout from the roughed surface. | M |
| **FW-05** | A scribe/scoring first pass of 0.2–0.5 mm shall be available to sever surface fibres before roughing; default ON for plywood, veneer, and cross-grain profiles. | M |
| **FW-06** | A sneak-up jog mode with 0.05 mm increments shall be provided for fitting joints to measured stock, operable via the increment buttons or the MPG handwheel in fine scale (ELE-09). | M |
| **FW-07** | Backlash strategy: firmware shall enforce the from-below approach of MOT-07 for every cutting height, including preset recall and cycle steps. | M |
| **FW-08** | Named presets (per bit / per joint) shall be storable relative to Z0 and retained across power cycles. Presets shall be locked (not deleted) whenever Z0 is invalid, and unlocked by a successful touch-off. | M |
| **FW-09** | The controller shall track Z0 validity. The following events shall invalidate Z0 and block all cutting cycles and presets until touch-off is repeated: bit-change mode entry, homing loss, E-stop actuation, supply brownout or power loss (FLT-04), a detected stall or missed-step event (FLT-01), a watchdog reset (FLT-03), or any other fault affecting position integrity. | M |
| **FW-10** | The firmware shall store the measured touch-off plate thickness as a calibrated parameter and apply it automatically during touch-off, so that Z0 refers to the true reference surface rather than the top of the plate. | M |
| **FW-11** | The Z0 reference surface shall be selectable between the table surface and the workpiece top surface, and the active reference shall be clearly displayed (ELE-08), since joint depths are commonly specified from the workpiece surface. | S |
| **FW-12** | After recalling a preset, MPG fine adjustments (ELE-09) shall be applied as a displayed trim relative to the preset value. An explicit save action shall be required to write the trimmed height back to the preset (per OPS-06); trims shall never be saved implicitly. The display shall show both the preset value and the current trim. | M |

# 7. Operating Modes and Canned Cycles (OPS)

## 7.1 Standard Cut Cycle — Scribe / Rough / Finish

| ID | Requirement | Priority |
|---|---|---|
| **OPS-01** | The standard cycle shall execute: home (if not homed) → touch-off (if Z0 invalid) → scribe pass → equalised roughing passes to D − F → finish pass at D. The lift shall advance to the next height only on operator confirmation (cycle-advance button) after each completed feed pass; an auto-advance option may be provided. Between-pass repositioning with the router running is permitted under the conditions of SAF-03. | M |
| **OPS-02** | During any feed pass the lift shall be motion-locked: jog, preset, and cycle inputs shall be ignored until the pass is confirmed complete. | M |
| **OPS-03** | Worked example (10 mm groove, R = 3 mm, F = 0.2 mm, scribe 0.3 mm): scribe at 0.3, then 9.5 mm remaining to D − F = 9.8 requires 4 equalised passes of 2.375 mm → roughing at 2.68 / 5.05 / 7.43 / 9.8 → finish at 10.0. The scheduler shall display the full pass list before starting. | S |

## 7.2 Dovetail Sequence

A dovetail bit undercuts (wider at the bottom), so incremental depth passes in the same slot are impossible: an intermediate-depth pass cuts a different profile, and the bit cannot be raised into an existing narrower slot, nor retracted mid-cut without destroying the work.

| ID | Requirement | Priority |
|---|---|---|
| **OPS-04** | The dovetail cycle shall be a two-bit sequence: (a) hog waste with a straight bit using the standard incremental scheduler, leaving ≈ 0.5 mm; (b) enter bit-change mode; (c) touch off the dovetail bit; (d) make a single full-depth dovetail pass. | M |
| **OPS-05** | The firmware shall refuse incremental depth passes for a slot flagged as a dovetail profile, and shall lock all lift motion for the duration of the dovetail pass. | M |
| **OPS-06** | Dovetail fit shall be adjustable in 0.05–0.1 mm height steps, and the dialled-in height shall be storable as a named per-bit preset so future joints repeat identically. | M |

## 7.3 Keyhole Cycle

A keyhole bit cuts a T-slot: it cannot exit sideways or be lifted out mid-slot, and must leave through the hole it entered. Unlike the dovetail, it enters vertically — a plunge the motorised lift performs under control.

| ID | Requirement | Priority |
|---|---|---|
| **OPS-07** | The keyhole canned cycle shall execute: operator confirms workpiece clamped against fence between stops and router running → controlled plunge (raise) into the stationary workpiece at the configured plunge rate to full depth → optional dwell for chip clearing → operator feeds workpiece the slot length to the stop → operator feeds back to the exact entry point → operator confirms → lift lowers the bit clear → prompt to stop router. | M |
| **OPS-08** | Plunge rate (default 2–3 mm/s), target depth, and dwell shall be programmable per keyhole preset. | M |
| **OPS-09** | The retract move shall be blocked until the operator confirms return to the entry point. | M |
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

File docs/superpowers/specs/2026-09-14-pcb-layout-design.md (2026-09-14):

# PCB layout — design

**Date:** 2026-09-14 · **Status:** approved in chat, awaiting spec review

## Goal

Lay out both carrier boards from the existing schematics and deliver fabrication-ready outputs:
routed `.kicad_pcb` files, a clean design rules check, and Gerber + drill zips for JLCPCB. The system
project is documentation only and gets no board.

## Inputs

| Input | Source |
| --- | --- |
| Netlist and footprints | `hardware/motion-carrier/motion-carrier.kicad_sch`, `hardware/panel-carrier/panel-carrier.kicad_sch` (generated, reviewed) |
| Devkit pin order | `hardware/tools/devkit.py`, verified against the HW-394 board on 2026-09-14 |
| Devkit row spacing | **25.4 mm — UNVERIFIED**, user to measure; marked on silkscreen and README |
| DIN-rail clips | Standard snap-on 35 mm DIN-rail PCB mounting clips — **exact hole spacing UNVERIFIED** |
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

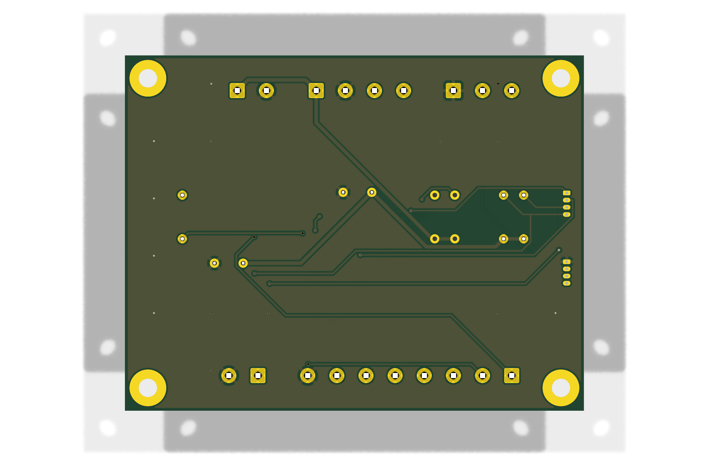
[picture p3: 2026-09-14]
hardware/panel-carrier/panel-carrier-bottom.png

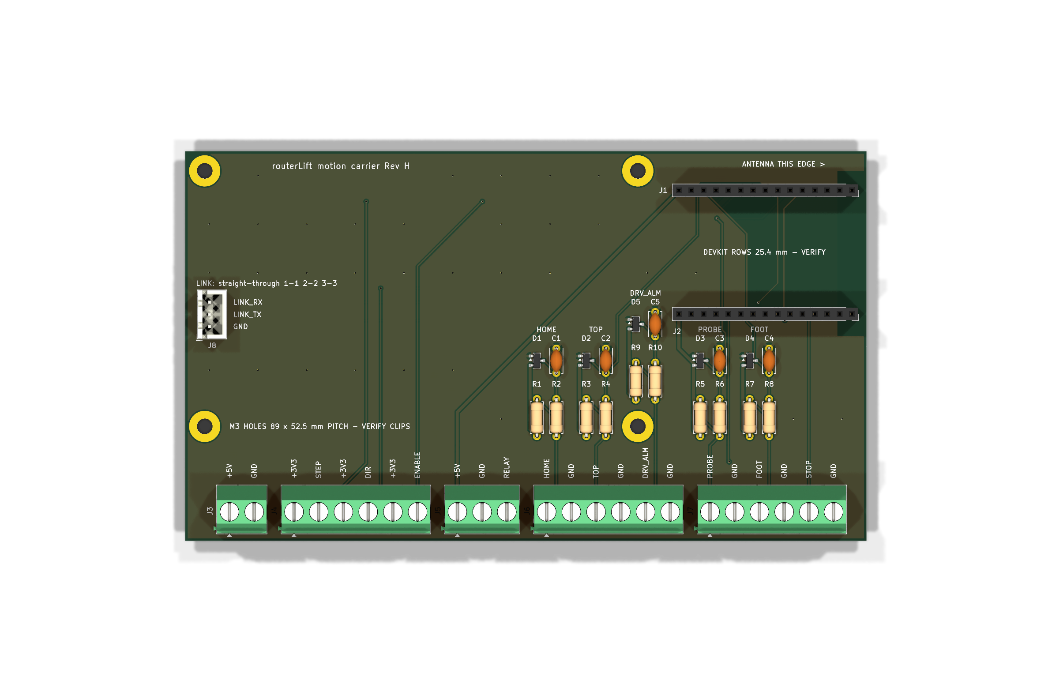
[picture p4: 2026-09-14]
hardware/motion-carrier/motion-carrier-top.png

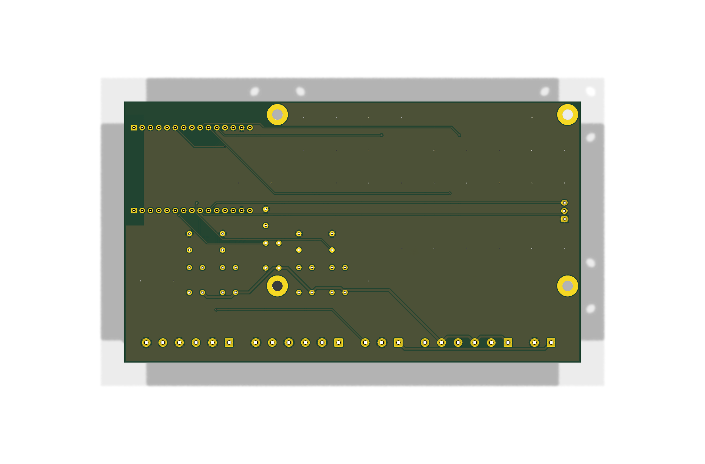
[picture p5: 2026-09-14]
hardware/motion-carrier/motion-carrier-bottom.png

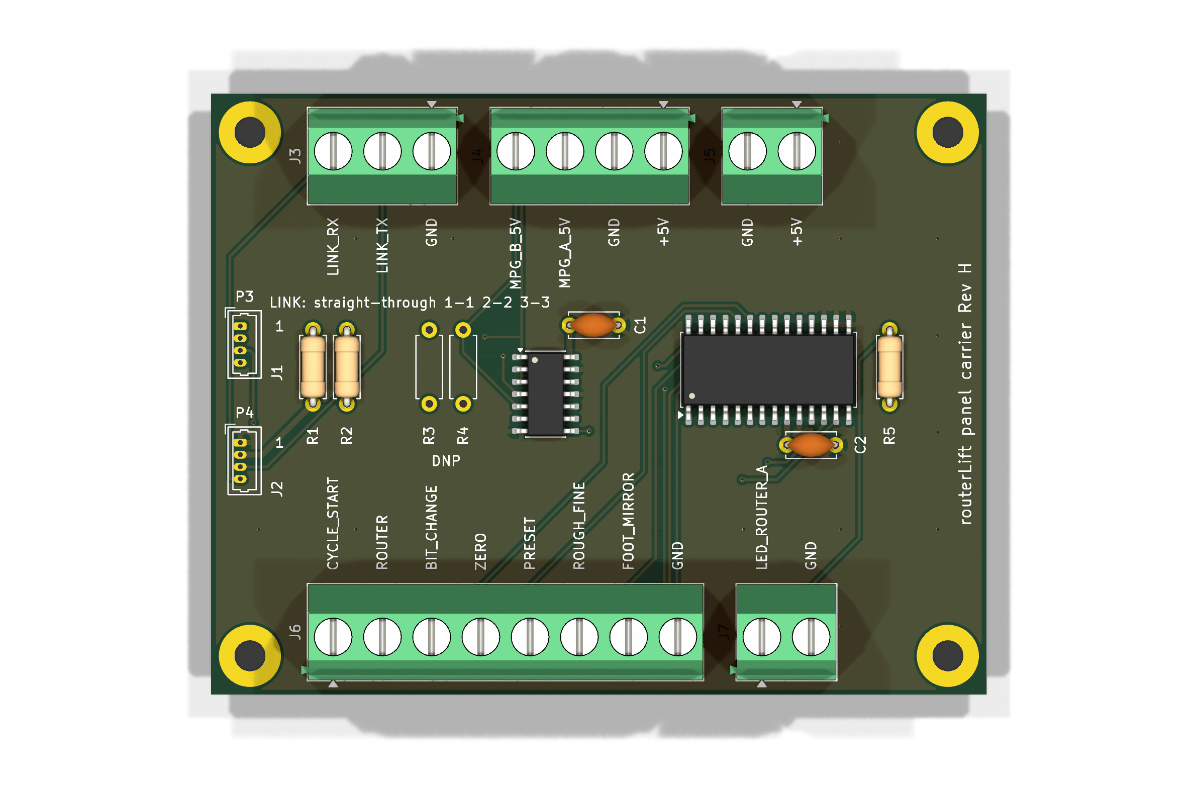
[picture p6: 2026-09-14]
hardware/panel-carrier/panel-carrier-top.png

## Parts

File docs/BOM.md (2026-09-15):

# Bill of Materials

Document: RTL-BOM-001 · Rev A · Companion to `SCHEMATIC-RevH.svg`

Closes the §14 open item *"Produce the bill of materials."* Blocks A–H match the
schematic blocks exactly.

**Status key:** ✅ in hand · 📦 ordered · 🛒 to buy · 🔭 future / DEV-01 closure

---

## A · Mains, E-stop and router power

| Qty | Item | Specification | Status | Notes |
| --- | --- | --- | --- | --- |
| 1 | E-stop button | Latching mushroom head, **NC**, mains-rated | 🛒 | SAF-01. Breaks L to **both** PSU and contactor. Not a logic-level button |
| 1 | Router contactor | **2-pole**, switching L and N; coil to suit relay module; contacts ≥2× router nameplate, AC-3 rated | 🛒 | PWR-03. Add arc suppression (RC snubber across contacts). ⚠️ **Coil voltage unverified** — the wiring map assumes 230 V AC; no part chosen yet |
| 1 | RCD / GFCI | To suit local installation | 🛒 | PWR-02 |
| 1 | Mains fuse + holder | Sized for PSU + router | 🛒 | In L, after the RCD and before the E-stop |
| 1 | Router socket | Switched, PE-bonded | 🛒 | L fed from contactor T1, N from T2 |
| 1 | **Bit-change key switch** | Keyed, 2-position, key removable in OFF only | 🛒 | **SAF-02 hardware interlock.** In series with the contactor coil, between the relay contact and A1. Key out = contactor physically cannot pull in, regardless of firmware |
| — | Mains cable, 3-core | To local code | 🛒 | PE to enclosure, lift frame **and** router socket |

## B · Power supply and rails

| Qty | Item | Specification | Status | Notes |
| --- | --- | --- | --- | --- |
| 1 | PSU | **24–36 V DC**, ≥50 % current margin | 🛒 | ⚠️ **Not 48 V.** TB6600 absolute max ≈40–42 V. This narrows §2.1's stated 24–48 V range and is a direct consequence of DEV-01 |
| 1 | DC-DC buck | 24–36 V → **5 V, ≥2 A** | 🛒 | Budget: panel ≈0.26 A (vendor spec), FluidNC ESP32 devkit up to ≈0.25 A with WiFi, relay module ≈70 mA, MPG ≈40 mA, shifter and expander negligible — **≈0.6–0.7 A**. ≥2 A is ≈3× margin, covering WiFi TX peaks and relay-coil inrush |
| — | +3.3 V (motion) | From the ESP32 devkit's onboard LDO | ✅ | Loads: 3 opto commons ≈24 mA + 5 conditioning pull-ups ≈4 mA |
| — | +3.3 V (panel) | From the panel's own regulator, P4 `3.3V` pin | ✅ | Feeds the 74LVC14 and MCP23017 only. ⚠️ **Never join it to the motion ESP32's 3.3 V** — join GND only |
| 1 | Star-ground point | At the PSU | 🛒 | PWR-04. One ground reference, not a daisy chain |

## C · Motion controller

| Qty | Item | Specification | Status | Notes |
| --- | --- | --- | --- | --- |
| 1 | ESP32 devkit | Classic ESP32 (**not** S3 — FluidNC does not run on S3) | 🛒 | Runs stock FluidNC; all machine definition in `config.yaml` |
| 1 | Relay module | 5 V, opto-isolated, drives the contactor coil | 🛒 | GPIO 4 via the `Relay` spindle (`M3`/`M5`). Verify it triggers reliably from 3.3 V logic at bench test 3 |

## D · Stepper drive

| Qty | Item | Specification | Status | Notes |
| --- | --- | --- | --- | --- |
| 1 | Stepper driver | **HLTNC TB6600** | ✅ | DIP: 1/8 µstep, 1600 pulse/rev. ⚠️ **Set 1.0–1.4 A/phase, NOT 2.8 A** — see below. → **1066.67 steps/mm** at the FML-P's 1.5 mm lead |
| 1 | Stepper motor | **NEMA 23 57HS76-3004A08**, 3.0 A/phase | ✅ | Coils RED/GRN/YEL/BLU → A+/A−/B+/B− |
| 1 | **Router lift body** | **sauter Fräslift FML-P** — 1.5 mm/rev, 65 mm travel, Ø43 mm neck | 🛒 | **€329 B-stock** (`II-SA-FML-P`) / €378 new. Self-locking (~2.3° lead angle). See `docs/MECHANICS-RevH.md` |
| 1 | Shaft coupling | **Zero-backlash jaw (spider) or Oldham**, motor shaft → hex stub | 🛒 | Backlash goes straight into MOT-02. **No universal joints** |
| 1 | Drive stub | Hex bit stock to suit the lift's lower socket | 🛒 | ⚠️ **Measure it** — the published 5 mm is the *upper* socket |
| 1 | Motor bracket | Rigid, below the lift, coaxial with the spindle | 🛒 | Fabricated. The coupling absorbs residual misalignment, not a bad bracket |
| 1 | Spindle motor | Ø43 mm neck, ≤5 kg, ≤1,100 W — AMB, Suhner or Mafell | 🛒 | Continuous-duty with soft start, unlike a handheld router |
| — | Motor cable | Shielded, 4-core, ≥0.75 mm² | 🛒 | Route **away** from limit wiring |

> ⚠️ **Tie `PUL+`/`DIR+`/`ENA+` to +3.3 V, not +5 V.** With a 5 V common, the ESP32's
> 3.3 V logic high leaves 1.7 V across the input optocoupler — above its ~1.2 V LED
> drop — so it never fully turns off. Result is missed steps at rapid, which under
> DEV-01 is *silent depth error*. Fallback if bench test 3 shows missed steps:
> 1× **74HCT245** buffer driving the inputs at a proper 5 V.

> ⚠️ **Set the driver to 1.0–1.4 A/phase, not 2.8 A.** The lift needs about
> 0.15 N·m; the 57HS76 delivers ~2 N·m. That >10× margin is a *hazard* — with no
> stall detection (DEV-01) an oversized motor will destroy the lift if it drives
> into a hard stop. Lower current also cuts the heat caused by `idle_ms: 255`.
> This supersedes Annex B.5's 2.8 A, chosen when the mechanics were unknown.

> ⚠️ **Wire `ENA−` to GPIO 14.** The RevG diagram marks `ENA±` n/c, which leaves the
> motor energised permanently with no idle reduction — an ENV-03 thermal risk
> over an 8-hour session, and no way for FluidNC to de-energise. One extra wire buys
> `disable_pin` and `$Stepper/IdleTime`.

## E · Sensors and input conditioning

| Qty | Item | Specification | Status | Notes |
| --- | --- | --- | --- | --- |
| 4 | Limit switch, mechanical | Roller lever, **NC**, e.g. Omron SS-5GL2 | ✅ | 2 fitted + 2 spares. Roller lever chosen for **overtravel**, not repeatability |
| 2 | Limit switch, inductive | **NPN NC** — `LJ12A3-4-Z/BY` | ✅ | ⚠️ Verify suffix. `/BX` = NPN NO, `/AY` and `/AX` are **PNP and source 24 V into the GPIO** |
| 1 | Touch-off probe plate | Conductive plate + croc clip | 🛒 | MOT-06. Record plate thickness (FW-10) |
| 1 | Foot switch | Momentary **NO**, industrial | 📦 | FluidNC GPIO 13, `macro0_pin`. Ordered 2026-09-13 |
| 2 | Hard mechanical stop | Shoulder / bolt the carriage cannot pass | 🛒 | One beyond each limit switch. Cheap insurance given DEV-01 |
| — | Sensor cable | Shielded twisted pair | 🛒 | Shield grounded at the **controller end only** |

### Conditioning circuit — ×5 (HOME, TOP, PROBE, FOOT, DRV_ALM)

| Qty | Item | Specification | Notes |
| --- | --- | --- | --- |
| 5 | Resistor | 10 kΩ, series | Limits an accidental 24 V to ~2 mA into the clamp |
| 5 | Resistor | 4.7 kΩ, pull-up to +3.3 V, **sensor/wire side** of the 10 kΩ | External rather than the internal ~45 kΩ, for rise time |
| 5 | Diode array | BAT54S, clamp to 3V3 / GND, **GPIO side** | What makes a mis-wired PNP sensor survivable |
| 5 | Capacitor | 100 nF to GND, **GPIO side** | 10 k × 100 n ≈ 1 ms RC — **ELE-04 met in hardware** |

**Topology:** `+3.3 V — 4.7 kΩ — wire node — 10 kΩ — GPIO node (BAT54S + 100 nF) — GPIO`. The
pull-up must sit on the wire side: on the GPIO side the 10 k / 4.7 k divider leaves a closed switch
at ≈2.2 V, which does not read LOW. Same as `docs/WIRING-RevH.md` diagram 4.

This one circuit accepts either switch type with no config change: wired NC, both
mechanical and inductive NPN idle LOW and read HIGH at the limit, and both fail safe
on a broken wire.

## F · Operator panel (HMI)

| Qty | Item | Specification | Status | Notes |
| --- | --- | --- | --- | --- |
| 1 | Touch display board | **Guition JC4827W543C** — XH-S3E N4R8 (ESP32-S3, 4 MB flash, 8 MB octal PSRAM), 4.3" 480×272 IPS, NV3041A **QSPI**, GT911 touch | ✅ | Matches spec Annex B.10. Rev H wrongly recorded an ESP32-4827S043; bench bring-up 2026-09-13 confirmed the JC4827W543C |
| — | Supply | 5 V, ≈260 mA | — | Vendor spec. From the buck (block B) |
| 1 | Panel cutout / bezel | 120 × 70.2 mm module (vendor spec) | 🛒 | Confirm against the board in hand |
| 2 | Pull-up resistor | 4.7 kΩ, to 3.3 V | 🛒 | MCP23017 I²C bus 1 (GPIO 15 SDA / 16 SCL) |
| 3 | Connector leads | **MX1.25 (Molex 51021-compatible) 4-pin, single-ended**, pre-crimped | 🛒 | For P2, P3, P4. Only one lead ships with the board. Check pin 1 on P4 before trusting colours (see `docs/BRINGUP-LOG.md`) |

> Only ten GPIOs reach the JST 1.25 mm connectors: P1 GND · RXD · TXD · +5V (power/console),
> P2 IO46 · IO9 · IO14 · IO5, P3 IO6 · IO7 · IO15 · IO16, P4 "UART1" GND · 3.3V · IO17 · IO18
> (P5 carries the same as P4 — use one). Allocation: UART on P4 (TX 18 → FluidNC RX 16, RX 17 ←
> FluidNC TX 17, plus GND); MPG A/B and I²C bus 1 on P3; spares 5/9/14 on P2; GPIO 46 is a boot
> strap, avoid. The touch I²C bus (8/4) and the TF card lines (10–13) reach no connector.

## G · MPG handwheel and level shifting

| Qty | Item | Specification | Status | Notes |
| --- | --- | --- | --- | --- |
| 1 | MPG handwheel | **ZS80-5E100S** — 80 mm dial, 100 PPR, 5 V, single-ended | ✅ | ⚠️ Spec B.8 records the ZS61 (60 mm). Same electricals, larger dial. Corrected in Rev H |
| 1 | Schmitt inverter | **74LVC14, powered from 3.3 V** (panel P4), two stages per channel — **SN74LVC14AD** (SOIC-14, fits panel carrier U1) | 📦 | Ordered 2026-09-15. 5 V-tolerant inputs, outputs swing 0–3.3 V, hysteresis for EMI. **Non-inverting** as configured. Check the marking says **LVC** |
| 1 | Level converter module (bench only) | 4-channel BSS138 bidirectional 3.3 V–5 V | 📦 | Ordered 2026-09-15 for the MPG bench test before the PCB: HV = buck 5 V, LV = panel 3.3 V, MPG A/B → HV1/HV2, LV1/LV2 → GPIO 6/7. **No Schmitt hysteresis** and does not fit U1 — not a substitute for the 74LVC14 in the build |
| — | MPG cable | Shielded, 4-core | 🛒 | ELE-10 |

> ⚠️ **74LVC14, not 74HCT14 — design error corrected 2026-09-13.** Rev A of this BOM specified a
> 74HCT14. That part needs a 4.5–5.5 V supply, so its outputs swing to 5 V — unsafe into the
> ESP32-S3 — and at 3.3 V it is out of spec. The 74LVC14 runs at 3.3 V with 5 V-tolerant inputs
> and the same Schmitt action. If a 74HCT14 has already arrived, do not connect it to the S3.

> ⚠️ **Level shifting is required here and only here.** The ESP32-S3 is not 5 V
> tolerant. Consequence for firmware: **`MPG::SIGNALS_INVERTED = false`** — the legacy
> value of `true` assumed PC817 optocouplers. Wrong value makes the wheel count backwards.

## H · Physical control panel

Six buttons with short/long-press doubling, giving twelve functions, plus the rough/fine
switch. Deliberately split across both boards.

| Qty | Item | Specification | Status | Notes |
| --- | --- | --- | --- | --- |
| 1 | I/O expander | **MCP23017-E/SO** (SOIC-28 wide, fits panel carrier U2), I²C, addr **0x20** | 📦 | On its own I²C bus 1, GPIO 15 SDA / 16 SCL (connector P3), 100 kHz, external 4.7 kΩ pull-ups to 3.3 V. Powered from P4 GND · 3.3V. The touch bus reaches no connector. **Costs two GPIOs.** 16 I/O, 10 spare. Ordered 2026-09-15 |
| 1 | I/O expander module (bench only) | MCP23017-E/SS breakout (SSOP-28) | 📦 | Ordered 2026-09-15 for bench testing. ⚠️ **Power from 3.3 V, never 5 V** — its I²C pull-ups go to VCC. Tie A0–A2 to GND (0x20) and confirm RESET is pulled high. SSOP does not fit U2 |
| 6 | Push button | Momentary NO, panel mount, ≥16 mm | 🛒 | Dry contacts to GND, expander internal pull-ups |
| 1 | Rough/fine selector | SPDT toggle → GND | 🛒 | ELE-09: 2 positions, not the legacy 3-band x1/x10/x100 |
| 1 | Indicator LED | Panel mount, + series resistor | 🛒 | ROUTER only — lit = live, blinking = warming |

### Button map

| Button | Board / pin | Short press | Long press |
| --- | --- | --- | --- |
| **STOP** | **FluidNC GPIO 21** → `feed_hold_pin` | Feed hold; router stays on | Soft reset (`0x18`) |
| CYCLE START | MCP23017 A0 | Start cycle / advance pass | — |
| ROUTER | MCP23017 A1 | Toggle router (`M3`/`M5`) | — |
| BIT CHANGE | MCP23017 A2 | Rapid to top, lock out | Exit, forcing re-probe |
| ZERO | MCP23017 A3 | Probe touch-off (`G38.2`) | Set zero here, no probe |
| PRESET | MCP23017 A4 | Recall active preset | Save current height |
| rough/fine | MCP23017 A5 | MPG scale | — |
| ROUTER LED | MCP23017 B0 | — | — |

**Why STOP is on the other board.** FluidNC's native control pins act with no HMI involvement, so
STOP halts motion even if the S3 has crashed or the UART has dropped. The other five depend on HMI
state — PRESET reads NVS on the S3, ZERO orchestrates the probe and Z0 validity, BIT CHANGE drives
an HMI state machine — so they cannot move without forking FluidNC.

> ⚠️ **STOP is a feed hold, not an E-stop.** The E-stop remains the mains-rated mushroom that kills
> the contactor (block A). Make them physically unmistakable — E-stop as a red mushroom on yellow,
> STOP as a flush round button, mounted well apart. **Two red mushrooms with different behaviours
> is a dangerous panel.**

**Side benefit:** keeping rough/fine and cycle start on the expander leaves three of the board's ten
connector GPIOs spare (5, 9, 14). `legacy/src/IOExpander.cpp` also becomes reusable —
port the polling and debounce, drop the board-ID logic.

## Enclosure, connectors and cable

| Qty | Item | Specification | Status | Notes |
| --- | --- | --- | --- | --- |
| 1 | Enclosure | **≥IP54** | 🛒 | ENV-02, MEC-06. Electronics outside the router cabinet |
| — | Connectors | Keyed, distinct types for LV vs mains | 🛒 | PWR-04 — segregation, and impossible to cross-plug |
| — | Cable gland set | To suit IP rating | 🛒 | |
| — | Ferrites | On motor and sensor runs | 🛒 | Helps ACC-07's zero-phantom-trigger test |
| 1 | DIN rail + terminal blocks | To suit enclosure | 🛒 | PSU, buck, ESP32, TB6600 and conditioning board on rail; terminals make the cable schedule practical |

## Test equipment

| Qty | Item | Specification | Status | Notes |
| --- | --- | --- | --- | --- |
| 1 | **Dial indicator** | 0.01 mm resolution + magnetic base | 🛒 | **The most important item still to buy.** Required for ACC-01–04, and the only way to measure the real screw lead and confirm `steps_per_mm`. Without it every depth figure stays an assumption |
| 1 | Bench PSU | Adjustable, **current-limited** | 🛒 | Set the limit low during bring-up so a wiring error trips it rather than destroying a board — relevant given the PNP hazard and the 24 V rail |
| 1 | Multimeter | Continuity + DC volts | 🛒 | Bench test 4: confirm the conditioning circuit swings 0–3.3 V and never exceeds it with the inductive sensor on 24 V |

## 🔭 Future — closing DEV-01

DEV-01 (TB6600 has no stall detection, so FLT-01 and the stall half of ACC-09 are
deferred) closes by **one** of:

| Option | Item | FluidNC impact | Pins |
| --- | --- | --- | --- |
| **A** | TMC5160 driver | Native — StallGuard, and closes the ELE-01 deviation too | SPI/UART |
| **B** | Closed-loop driver (CL57T, iHSS, integrated NEMA 23) | **One digital input.** Stock FluidNC, still step/dir | 1 |
| **C** | ~~Raw encoder into the ESP32~~ | ✗ **Not supported** — no closed-loop feedback for step/dir axes. Would require forking FluidNC | — |

**Reserved now, at the cost of one wire:** GPIO 35 as `DRIVER_ALARM`, wired NC through
the same conditioning circuit as the limits. GPIO 34 held alongside it. Both are pins
freed by moving the MPG to the HMI board. With these reserved, option B becomes a
`config.yaml` edit rather than a rewire.

---

## Deviations from RevG recorded here

| Item | RevG says | As built | Where corrected |
| --- | --- | --- | --- |
| Display board | JC4827W543C, NV3041A QSPI | **Same — not a deviation.** Rev H's ESP32-4827S043 record was wrong (bench, 2026-09-13) | Annex B.10 stands |
| Handwheel | ZS61 (60 mm dial) | **ZS80** (80 mm dial), same 100 PPR | Rev H, Annex B.8 |
| PSU range | 24–48 V (ELE-01) | **24–36 V** | Already noted §2.1 under DEV-01 |
| TB6600 common | +5 V | **+3.3 V** | Rev H, Annex B.9 |
| `ENA±` | n/c | **Wired to GPIO 14** | Rev H, Annex B.9 |
| MPG pins | FluidNC GPIO 34/35 | **HMI GPIO 6/7**; 34/35 reserved for feedback | Rev H, Annex B.9 |
| MPG level shifter | — | **74LVC14 at 3.3 V** (BOM Rev A's 74HCT14 was a design error) | This BOM, block G |

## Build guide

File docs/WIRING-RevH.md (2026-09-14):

# routerLift wiring map — Rev H

Every connection in the split design: stock FluidNC on a classic ESP32 moves the lift, and an
ESP32-S3 touch panel drives it over UART. Pin numbers come from `firmware/config.yaml` (verified on
the bench, 2026-09-13) and `hmi/include/pins.h`. **If this page and those files disagree, the files
win.**

Node colours: red = mains 230 V · orange = 24–36 V DC · yellow = +5 V · blue = 3.3 V logic ·
dashed = reserved or not yet fitted.

## Before power-up

| # | Check |
| --- | --- |
| 1 | **PSU 24–36 V only.** A 48 V supply destroys the TB6600 (abs max ≈40–42 V) |
| 2 | **TB6600 PUL+ DIR+ ENA+ to 3.3 V, not 5 V.** At 5 V the input opto never turns fully off, so steps go missing without any error |
| 3 | **Inductive sensors NPN only.** `LJ12A3-4-Z/BY` is right; any `/A…` suffix is PNP and puts 24 V on the GPIO |

## 1 · Power and system overview

One PSU feeds everything low-voltage. The E-stop sits in the mains supply, ahead of both
controllers, so neither can override it. Join every 0 V at a single star point next to the PSU.

```mermaid
flowchart LR
  classDef mains fill:#F6D5D1,stroke:#B3261E,color:#3A0B07
  classDef v24 fill:#F9E0C4,stroke:#C25E00,color:#3D1E00
  classDef v5 fill:#F5EBC2,stroke:#8C7000,color:#2F2500
  classDef v33 fill:#D6E6F2,stroke:#2C5F8A,color:#0E2436
  classDef board fill:#DDE4DF,stroke:#39433F,color:#15201B,stroke-width:2px

  subgraph MAINS["Mains 230 V"]
    INLET["Inlet L / N / PE<br/>via RCD"] --> FUSE["Fuse"] --> ESTOP["E-STOP mushroom<br/>NC, latching"]
  end
  ESTOP -->|"L, N"| PSU["PSU 24–36 V DC<br/>NOT 48 V"]
  ESTOP -->|"L, N"| CONT["Contactor, 2-pole<br/>see diagram 5"]
  CONT --> SOCKET["Router socket"]

  PSU -->|"24–36 V"| TB["TB6600 driver"]
  PSU -->|"24–36 V"| BUCK["Buck converter<br/>5 V, 2 A or more"]
  PSU -.->|"24 V"| IND["Inductive NPN<br/>limit sensors, if used"]

  BUCK -->|"5 V to VIN"| ESP["Motion ESP32<br/>FluidNC"]
  BUCK -->|"5 V"| HMI["ESP32-S3 panel<br/>4.3 in touch"]
  BUCK -->|"5 V"| RELAY["5 V relay module"]
  BUCK -->|"5 V"| MPG["MPG handwheel"]

  ESP -->|"3V3 pin"| COMMON["TB6600 PUL+ DIR+ ENA+<br/>input pull-ups"]
  ESP ---|"UART  TX17 to RX16"| HMI
  ESP -->|"GPIO 4"| RELAY
  RELAY -->|"coil"| CONT
  TB -->|"4-core shielded"| MOTOR["NEMA 23<br/>57HS76"]
  GND(("Star ground<br/>at the PSU"))

  class INLET,FUSE,ESTOP,CONT,SOCKET mains
  class PSU,TB,IND v24
  class BUCK,RELAY,MPG v5
  class COMMON v33
  class ESP,HMI,MOTOR,GND board
```

## 2 · Motion controller ESP32 — every pin

Everything that starts motion or protects the machine lands here, so it keeps working when the
panel has crashed or the UART link has dropped.

```mermaid
flowchart LR
  classDef board fill:#DDE4DF,stroke:#39433F,color:#15201B,stroke-width:2px
  classDef v33 fill:#D6E6F2,stroke:#2C5F8A,color:#0E2436
  classDef field fill:#FFFFFF,stroke:#6B7570,color:#1C2321
  classDef reserved fill:#FFFFFF,stroke:#9AA39E,color:#5A6661,stroke-dasharray:4 3

  subgraph INPUTS["Inputs"]
    HOME["Bottom switch<br/>HOME and neg limit, NC"]
    TOP["Top switch<br/>pos limit, NC"]
    PROBE["Touch-off plate"]
    FOOT["Foot switch, NO"]
    STOP["STOP button, NO<br/>flush, feed hold"]
    DRV["Driver ALARM<br/>future closed-loop"]
  end

  COND["Conditioning<br/>one channel each<br/>diagram 4"]

  HOME --> COND
  TOP --> COND
  PROBE --> COND
  FOOT --> COND
  DRV -.-> COND

  COND -->|"GPIO 33"| ESP
  COND -->|"GPIO 25"| ESP
  COND -->|"GPIO 32"| ESP
  COND -->|"GPIO 13"| ESP
  COND -.->|"GPIO 35"| ESP
  STOP -->|"GPIO 21 direct, to GND"| ESP

  ESP["ESP32 DevKit WROOM-32<br/>stock FluidNC v4.1.0"]

  subgraph OUTPUTS["Outputs"]
    PUL["TB6600 PUL−"]
    DIR["TB6600 DIR−"]
    ENA["TB6600 ENA−"]
    RIN["Relay module IN"]
    RX["Panel GPIO 17 RX"]
  end
  TX["Panel GPIO 18 TX"]

  ESP -->|"GPIO 26 STEP"| PUL
  ESP -->|"GPIO 27 DIR"| DIR
  ESP -->|"GPIO 14 ENABLE"| ENA
  ESP -->|"GPIO 4 router"| RIN
  ESP -->|"GPIO 17 TX"| RX
  TX -->|"GPIO 16 RX"| ESP
  RES34["GPIO 34<br/>held for feedback"] -.- ESP

  class ESP board
  class COND,PUL,DIR,ENA,RIN,RX,TX v33
  class HOME,TOP,PROBE,FOOT,STOP field
  class DRV,RES34 reserved
```

| GPIO | Signal | Goes to | FluidNC key |
| --- | --- | --- | --- |
| 26 | STEP | TB6600 PUL− | `step_pin` |
| 27 | DIR | TB6600 DIR− | `direction_pin` |
| 14 | ENABLE | TB6600 ENA− | `disable_pin` |
| 4 | Router on/off | Relay module IN | `Relay: output_pin` |
| 33 | Bottom limit, homes here | Conditioner ← switch | `limit_neg_pin` |
| 25 | Top limit | Conditioner ← switch | `limit_pos_pin` |
| 32 | Probe plate | Conditioner ← plate; croc clip on bit to GND | `probe: pin` (active low) |
| 13 | Foot switch | Conditioner ← switch to GND | `macro0_pin` (active low) |
| 21 | STOP (feed hold) | Button to GND, internal pull-up | `feed_hold_pin` (active low) |
| 17 | UART TX | Panel GPIO 17 (RX) | `uart1: txd_pin` |
| 16 | UART RX | Panel GPIO 18 (TX) | `uart1: rxd_pin` |
| 35 | Driver alarm, reserved | Conditioner, wired NC | not configured yet |
| 34 | Reserved | nothing; held for feedback hardware | — |
| 3V3 | 3.3 V out | TB6600 PUL+ DIR+ ENA+, conditioner pull-ups | — |
| VIN · GND | Power in | Buck 5 V · star ground | — |

## 3 · TB6600 driver and motor

Common-anode wiring: the + terminals share 3.3 V and the ESP32 pulls each − terminal low to switch
it. DIP switches: 1/8 microstep (1600 pulses/rev), **1.0–1.4 A per phase**.

```mermaid
flowchart LR
  classDef v33 fill:#D6E6F2,stroke:#2C5F8A,color:#0E2436
  classDef v24 fill:#F9E0C4,stroke:#C25E00,color:#3D1E00
  classDef board fill:#DDE4DF,stroke:#39433F,color:#15201B,stroke-width:2px
  classDef coil fill:#FFFFFF,stroke:#39433F,color:#15201B

  V33["ESP32 3V3 pin"]
  G26["ESP32 GPIO 26"]
  G27["ESP32 GPIO 27"]
  G14["ESP32 GPIO 14"]
  PSUP["PSU +24–36 V"]
  PSUN["PSU 0 V"]

  subgraph TB6600["TB6600 · 1/8 step · 1.0–1.4 A"]
    PULP["PUL+"]
    PULM["PUL−"]
    DIRP["DIR+"]
    DIRM["DIR−"]
    ENAP["ENA+"]
    ENAM["ENA−"]
    VCC["VCC"]
    GNDT["GND"]
    AP["A+"]
    AM["A−"]
    BP["B+"]
    BM["B−"]
  end

  V33 --> PULP
  V33 --> DIRP
  V33 --> ENAP
  G26 --> PULM
  G27 --> DIRM
  G14 --> ENAM
  PSUP --> VCC
  PSUN --> GNDT

  AP -->|"RED"| MOTOR
  AM -->|"GRN"| MOTOR
  BP -->|"YEL"| MOTOR
  BM -->|"BLU"| MOTOR
  MOTOR["NEMA 23 57HS76-3004A08<br/>shielded 4-core, away from sensor runs"]

  class V33,G26,G27,G14,PULP,PULM,DIRP,DIRM,ENAP,ENAM v33
  class PSUP,PSUN,VCC,GNDT v24
  class AP,AM,BP,BM coil
  class MOTOR board
```

> ⚠️ **Why 1.0–1.4 A, not the motor's 3.0 A.** The lift needs about 0.15 N·m and this motor makes
> about 2 N·m. There is no stall detection, so at full current a bad move drives the lift into its
> hard stop with more than ten times the force it needs.

## 4 · Input conditioning — one channel

Build five identical channels: HOME (33), TOP (25), PROBE (32), FOOT (13) and DRIVER ALARM (35).
The same channel takes a mechanical switch or an NPN inductive sensor with no config change.

```mermaid
flowchart LR
  classDef v33 fill:#D6E6F2,stroke:#2C5F8A,color:#0E2436
  classDef v24 fill:#F9E0C4,stroke:#C25E00,color:#3D1E00
  classDef part fill:#FFFFFF,stroke:#39433F,color:#15201B
  classDef board fill:#DDE4DF,stroke:#39433F,color:#15201B,stroke-width:2px

  subgraph MECH["Option A · mechanical roller switch"]
    MCOM["COM terminal"] --> MG["GND"]
    MNC["NC terminal"]
  end
  subgraph NPN["Option B · inductive NPN NC"]
    BRN["Brown"] --> P24["+24 V"]
    BLU["Blue"] --> P0["0 V"]
    BLK["Black = signal"]
  end

  MNC --> WIRE
  BLK -.-> WIRE
  WIRE["Signal wire<br/>shielded pair, shield to GND<br/>at controller end only"]

  V33["+3.3 V"] --> RPU["4.7 kΩ pull-up"]
  RPU --> WIRE
  WIRE --> RS["10 kΩ series"]
  RS --> NODE(("input node"))
  NODE --> CLAMP["BAT54S<br/>clamps to 3V3 and GND"]
  NODE --> CAP["100 nF to GND<br/>about 1 ms filter"]
  NODE --> GPIO["ESP32 GPIO"]

  class V33,GPIO v33
  class P24 v24
  class RPU,RS,CLAMP,CAP,MCOM,MNC,MG,BRN,BLU,BLK,P0 part
  class NODE board
```

**Reading it:** in normal use the NC contact or NPN output holds the wire at 0 V, so the GPIO reads
LOW. At the limit, or if a wire breaks, the pull-up takes it HIGH and FluidNC stops. That is why the
bare board alarmed until GPIO 33 and 25 were jumpered to GND.

**Probe and foot switch** use the same channel but are normally open: plate or pedal to the signal
wire, other side to GND. Their FluidNC pins are set `:low`, so pressing reads as active.

> ⚠️ **Pull-up on the sensor side, filter on the GPIO side.** The 4.7 kΩ pull-up goes on the
> wire side of the 10 kΩ series resistor; the BAT54S clamp and 100 nF go on the GPIO side. Put the
> pull-up on the GPIO side instead and a closed switch only pulls the input to about 2.2 V (a
> 10 k / 4.7 k divider), which does not read as LOW. `docs/BOM.md` block E specifies the same.

## 5 · Mains and router switching

Three things must all agree before the router runs: the E-stop is out, the bit-change key is in,
and FluidNC has set GPIO 4 with `M3`. Only the last one is software. The contactor is 2-pole: it
switches both L and N to the router socket, so the router is isolated whichever way round the
supply is wired.

```mermaid
flowchart LR
  classDef mains fill:#F6D5D1,stroke:#B3261E,color:#3A0B07
  classDef v5 fill:#F5EBC2,stroke:#8C7000,color:#2F2500
  classDef v33 fill:#D6E6F2,stroke:#2C5F8A,color:#0E2436
  classDef pe fill:#DFF0DA,stroke:#3C7A2E,color:#12300A

  L["Mains L"] --> F["Fuse"] --> E["E-STOP<br/>NC, latching"]
  E --> K["Contactor main contact<br/>L1 to T1"]
  K --> SL["Router socket L"]
  SNUB["RC snubber<br/>across the contact"] --- K

  E --> RC["Relay module contact<br/>COM to NO"]
  RC --> KEY["Bit-change KEY switch<br/>in series with coil"]
  KEY --> A1["Contactor coil A1"]
  A2["Contactor coil A2"] --> N["Mains N"]
  N --> K2["Contactor main contact<br/>L2 to T2"]
  K2 --> SN["Router socket N"]

  G4["ESP32 GPIO 4"] --> RIN["Relay module IN"]
  B5["Buck 5 V"] --> RVCC["Relay module VCC"]
  G0["Star ground"] --> RGND["Relay module GND"]

  PE["Mains PE"] --> PE1["Enclosure"]
  PE --> PE2["Lift frame"]
  PE --> PE3["Router socket PE"]

  class L,F,E,K,K2,SL,SNUB,KEY,RC,A1,A2,N,SN mains
  class B5,RVCC,RGND,G0 v5
  class G4,RIN v33
  class PE,PE1,PE2,PE3 pe
```

> ⚠️ **Check against your parts.** This drawing assumes a **230 V AC contactor coil** — an
> unverified assumption; no contactor has been chosen. For a 24 V
> coil, feed the key switch and relay contact from the 24 V rail instead of mains L, and return A2
> to 0 V. Size the contactor at twice the router's nameplate current or more. Mains cable and
> connectors must be a different type from every low-voltage run, so they cannot be cross-plugged.

## 6 · Operator panel

The panel holds everything that depends on job state: presets, zero validity, cycles. The board is a
Guition JC4827W543C, which brings only ten GPIOs out to JST 1.25 mm connectors. Five buttons and
the selector go through an MCP23017 on its own I²C bus, because the touch bus reaches no connector.

```mermaid
flowchart LR
  classDef board fill:#DDE4DF,stroke:#39433F,color:#15201B,stroke-width:2px
  classDef v33 fill:#D6E6F2,stroke:#2C5F8A,color:#0E2436
  classDef v5 fill:#F5EBC2,stroke:#8C7000,color:#2F2500
  classDef field fill:#FFFFFF,stroke:#6B7570,color:#1C2321
  classDef warn fill:#FFE9A8,stroke:#B37400,color:#3A2600

  MPG["MPG ZS80<br/>100 PPR, 5 V"] -->|"A, B at 5 V"| LS["74LVC14 at 3.3 V<br/>two stages per channel"]
  P4P["P4 GND and 3.3V"] --> LS
  P4P --> MCP
  B5["Buck 5 V"] --> MPG
  LS -->|"A to GPIO 6, P3"| S3
  LS -->|"B to GPIO 7, P3"| S3

  S3["ESP32-S3 panel<br/>Guition JC4827W543C"]
  S3 -->|"SDA 8, SCL 4<br/>on board only"| TBUS["I²C bus 0"]
  TBUS --> GT["GT911 touch<br/>0x5D, on board"]
  S3 -->|"SDA 15, SCL 16, P3"| BUS["I²C bus 1<br/>4.7 kΩ pull-ups to 3.3 V"]
  BUS --> MCP["MCP23017<br/>address 0x20"]

  A0["A0 CYCLE START"] --> MCP
  A1["A1 ROUTER"] --> MCP
  A2["A2 BIT CHANGE"] --> MCP
  A3["A3 ZERO"] --> MCP
  A4["A4 PRESET"] --> MCP
  A5["A5 rough / fine toggle"] --> MCP
  A6["A6 foot switch mirror<br/>release edge"] -.-> MCP
  MCP -->|"B0"| LED["ROUTER LED<br/>with series resistor"]

  S3 -->|"GPIO 18 TX"| FRX["Motion ESP32 GPIO 16"]
  FTX["Motion ESP32 GPIO 17"] -->|"GPIO 17 RX"| S3
  STOP["STOP button"] -.->|"wires to motion GPIO 21,<br/>not to this board"| FST["Motion ESP32"]

  class S3,GT,MCP board
  class BUS,TBUS,FRX,FTX,FST,LS,P4P v33
  class MPG,B5 v5
  class A0,A1,A2,A3,A4,A5,A6,LED,STOP field
```

| Panel pin | Signal | Notes |
| --- | --- | --- |
| GPIO 18 (P4) | UART TX → motion GPIO 16 | 3.3 V both ends, no shifter. Also join GND (P4) |
| GPIO 17 (P4) | UART RX ← motion GPIO 17 | 115200 baud. P5 carries the same signals — use one, not both |
| GPIO 6 · 7 (P3) | MPG A · B | Must arrive at 3.3 V |
| GPIO 15 · 16 (P3) | I²C bus 1 SDA · SCL | MCP23017 only, 100 kHz, 4.7 kΩ pull-ups to 3.3 V |
| P4 GND · 3.3V | Power for shifter and expander | P3 has no power pins. Never join this 3.3 V to the motion ESP32's 3.3 V — GND only |
| P1 GND · +5V | Panel supply from the buck | 5 V, ≈260 mA (vendor spec) |
| MCP A0–A5 | Buttons and selector | Dry contact to GND, internal pull-ups |
| MCP A6 | Foot switch mirror | Plan still unverified — see `firmware/README.md` |
| MCP B0 | ROUTER LED | Lit = live, blinking = warming up |
| GPIO 5 · 9 · 14 (P2) | Spare | GPIO 46 (P2) is a boot strap: never drive it at power-up |
| GPIO 8 · 4 | Touch I²C | On-board GT911 only; reaches no connector |

Connectors are JST 1.25 mm (MX1.25). Only one lead ships with the board: buy single-ended
**MX1.25 / Molex 51021-compatible 4-pin** leads for the rest (`docs/BOM.md` block F).

> ⚠️ **MPG level shifter is a 74LVC14 powered from 3.3 V, not a 74HCT14.** A 74HCT14 needs
> 4.5–5.5 V, so its outputs swing to 5 V, which can damage the S3's inputs. The 74LVC14 has
> 5 V-tolerant inputs and the same Schmitt hysteresis; two stages per channel stay non-inverting,
> so `SIGNALS_INVERTED = false` is unchanged. Corrected in `docs/BOM.md` block G.

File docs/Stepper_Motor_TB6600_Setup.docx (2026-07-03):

Stepper Motor & Driver Setup Reference

HLTNC 57HS76-3004A08 (NEMA 23) + HLTNC TB6600 Driver — July 2026

# 1. Motor Details

Parameter | Value
Model | HLTNC 57HS76-3004A08-D21-22
Frame | NEMA 23 (57 mm), 76 mm body length
Type | Bipolar, 4-wire
Rated current | 3.0 A per phase
Driver used | HLTNC TB6600 (DC 9–42 V)

# 2. Motor Wiring (per label on motor)

Wire Colour | Coil / Polarity | TB6600 Terminal
Red | Coil A + | A+
Green | Coil A − | A−
Yellow | Coil B + | B+
Blue | Coil B − | B−

- Motor runs backwards? Swap Red and Green (or invert direction in software).
- Motor buzzes/jitters without turning? A wire is on the wrong coil — recheck pairs.

# 3. TB6600 Signal & Power Terminals

Terminal | Function
PUL+ / PUL− | Step pulse input
DIR+ / DIR− | Direction input
ENA+ / ENA− | Enable (optional — leave unconnected to keep driver enabled)
VCC / GND | Motor power supply, DC 9–42 V
A+ A− B+ B− | Motor coils (see wiring table above)

# 4. DIP Switch Settings (FINAL)

Important: on this driver, DOWN = ON, UP = OFF (marked “ON↓” on the switch block). Change switches only with power off.

Switch | Setting | Lever Position
SW1 | OFF | Up
SW2 | ON | Down
SW3 | OFF | Up
SW4 | OFF | Up
SW5 | OFF | Up
SW6 | ON | Down

This gives:

- SW1–SW3 = OFF / ON / OFF → 1/8 microstepping, 1600 pulses per revolution.
- SW4–SW6 = OFF / OFF / ON → 2.8 A phase current (recommended for a 3.0 A motor on a TB6600 — cooler, near-full torque).

## Optional: full 3.0 A setting

If more torque is needed and the driver has good cooling: SW4 = OFF (up), SW5 = ON (down), SW6 = OFF (up). Expect more heat — heatsink/airflow required.

# 5. Notes

- Always verify against the table printed on the driver case — clone units can differ.
- Set current with power off; never disconnect motor wires while powered.
- At 1600 pulses/rev, one full revolution = 1600 step pulses from the controller.
- Give the TB6600 airflow at 2.8–3.0 A — it can misbehave when overheated.

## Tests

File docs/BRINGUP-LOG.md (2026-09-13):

# Bench bring-up log

Where the hardware actually stands, session by session. Newest first. The design docs say what
the machine *should* be; this file says what has been *proven on the bench*.

---

## 2026-09-13 (later) — Step B: UART link ✅ passed

Supplied P4 lead wired as planned (red GND, blue IO17 → D17, black IO18 → D16, yellow
insulated), D33/D25 jumpered to GND.

| Check | Result |
| --- | --- |
| Link comes up | ✅ screen shows **LINK**, Z 0.00 mm, message "ALARM – re-home required"; log `[LINK] up`, `ALARM Z= 0.000 … LINK … Z0=INVALID(alarm)` |
| Link loss | ✅ pressing FluidNC **EN** → immediate `[LINK] LOST - feed hold sent, Z0 invalidated` |
| Recovery | ✅ link returns on its own; **Z0 stays INVALID(link lost)** until re-probed, as FW-09 requires |

**Bug found and fixed:** the HMI never polled for status. `LinkCfg::POLL_MS` existed but was
unused, and FluidNC's `report_interval_ms` only reports *on change* — so an idle machine sitting
in Alarm sends nothing and the screen showed NO LINK with correct wiring. `Link::update()` now
sends the `?` realtime byte every 100 ms. This also settles `firmware/README.md` item 2: the
interval setting exists but is not a heartbeat; polling is required.

**FluidNC console without USB:** the FluidNC board was running (linked, web UI up at
`routerlift.local`) but its USB serial port did not appear on the Mac — likely a charge-only
cable. Not needed: FluidNC's **telnet console on port 23** gives the same `?`, `$` commands and
messages over WiFi (`routerlift.local:23`). Queried that way it reported
`<Alarm|MPos:0.000,0.000,0.000|FS:0,0|Pn:Z>`. `$Limits` (exit with `!`, not any key — it
otherwise keeps running) showed the **positive limit, GPIO 25**, active. Reseating did not clear
it; **swapping the D25 and D33 jumper wires did** — status back to `<Alarm|…|FS:0,0>` with no
active inputs. GPIO 25 is fine; the cause was a poor-contact jumper. Bench jumpers are unreliable
for limit inputs; real sensors go through proper terminals.

---

## 2026-09-13 — motion board and screen board, bare

**Paused here for about a week, waiting on the MPG level shifters.**

### Resume checklist (start here next session)

1. **Before wiring the level shifters, check which part arrived.** The design now specifies a
   **74LVC14 powered from 3.3 V** (5 V-tolerant inputs, Schmitt hysteresis, two stages per
   channel = non-inverting, `SIGNALS_INVERTED = false`). The BOM originally said 74HCT14: that
   needs a 5 V supply and drives 5 V into the ESP32-S3. If a 74HCT14 is what arrived, do not
   connect its outputs to the S3.
2. ~~**Step B — join the two boards over UART.**~~ ✅ Passed later the same day — see the entry
   above. Next is the MPG through the shifters on P3 (GPIO 6/7).
3. **Foot-switch edge test — can run now, no pedal needed** (pedal ordered 2026-09-13). Decides
   whether FluidNC's `macro0_pin` fires on release as well as press, i.e. whether the MCP A6
   mirror wire is needed for the dead-man retract (`firmware/README.md`, "the foot switch needs
   both edges"). Nothing can move: FluidNC is in Alarm and the macro only prints.
   1. Over WiFi (`telnet routerlift.local 23`): `$Macro0=$G` — a print-only command.
   2. Touch a jumper **D13 → GND** (= press), hold 2 s, remove (= release). Repeat twice.
   3. Watch the console: `[GC:…]` parser-state output on press only → fires on assert only, keep
      the A6 mirror; output on press **and** release → both edges fire, the mirror can go.
   4. Restore: `$Macro0=` (empty). Record the result here and in `firmware/README.md` item 4.
4. **Push status:** everything below is committed and pushed.

### Motion controller — FluidNC ESP32 ✅ bare-board acceptance passed

| Item | Result |
| --- | --- |
| Board | 30-pin USB-C devkit, ESP32-D0WD-V3 **rev 3.1**, CH340, 4 MB, MAC `d4:8a:fc:a4:a9:f8` |
| Firmware | **FluidNC v4.1.0 (esp32-wifi)**, via installer.fluidnc.com |
| Config | `firmware/config.yaml` parses clean. Fix needed and made: spindle key is `Relay:`, not `relay_spindle:`; no comments or quotes on section-header lines |
| Verified | Z axis 0–65 mm, step 26 / dir 27 / disable 14, limits 33/25, STOP 21, foot 13, probe 32, relay 4, UART1 17/16 @ 115200 with 100 ms reports |
| Limits | Unwired → `ALARM: Hard Limit` + `Pn:Z` (correct, NC wiring). D33 + D25 jumpered to GND → clears, boot ends at `ALARM:14` Unhomed (correct, `must_home`) |
| Network | Joins home WiFi as `routerlift.local` / **192.168.1.82**, falls back to AP `FluidNC` (default password `12345678` — change before commissioning, or `$WiFi/Mode=Off`) |

Full detail and flashing steps: `firmware/README.md`.

### Screen board — ✅ display and touch working, ⏸ not yet linked

**The board is a Guition JC4827W543C, not the ESP32-4827S043 that Rev H recorded.** The Rev G
spec had it right. Firmware built for the RGB-parallel Sunton board booted cleanly and showed
nothing. Identified from strings in the factory demo (`guition.com`, `Arduino_ESP32QSPI`) and
the board silkscreen. Docs corrected in commit `e676627`.

| Item | Result |
| --- | --- |
| Module | sparkleIoT XH-S3E **N4R8** — ESP32-S3 rev 0.2, 4 MB flash, **8 MB octal PSRAM**, MAC `a4:cb:8f:ec:16:7c` |
| USB | Native S3 USB → `/dev/cu.usbmodem*`. Upload auto-resets; download mode (hold BOOT, tap RST) only needed if the app has hung |
| Factory demo | Backed up in full: `~/Documents/routerLift-firmware-backups/screen-original-dashboard.bin` (4 MB, sha256 `ba5adbf6…6f2f`). Restore: `esptool.py --chip esp32s3 write_flash 0 screen-original-dashboard.bin` |
| Display | NV3041A over QSPI (CS 45, SCK 47, D0–D3 21/48/40/39), backlight GPIO 1. Main screen renders |
| Touch | GT911 on SDA 8 / SCL 4, INT 3, RST 38. **Both axes mirrored** — flipped in `Display.cpp`. Top-left tap reads ~25,25 |
| I²C | Touch on bus 0 (8/4, on-board only). MCP23017 on **bus 1, GPIO 15/16** — initialises, reports not found (not wired) |
| Build fixes | `huge_app.csv` partitions (stock table was 8 MB layout → boot loop); `qio_opi` confirmed (quad → PSRAM ID read error) |
| Diagnostics | `pio run -e hmi-diag` — skips I²C, waits for USB, logs display bring-up, colour cycle |

#### Connector map (silkscreen, JST 1.25 mm / MX1.25, 4-pin)

| Connector | Pins | Allocated to |
| --- | --- | --- |
| P1 | GND · RXD · TXD · +5V | UART0 + 5 V in |
| P2 | IO46 · IO9 · IO14 · IO5 | spares 5, 9, 14 — **avoid 46** (boot strap) |
| P3 | IO6 · IO7 · IO15 · IO16 | **MPG A/B = 6/7**, **MCP I²C SDA/SCL = 15/16** |
| P4 "UART1" | GND · 3.3V · IO17 · IO18 | **UART to FluidNC** |
| P5 | GND · 3.3V · IO17 · IO18 | same as P4 — use one, never both |

P3 has no power pins; take GND and 3.3 V for the shifter and expander from P4. The MCP23017 bus
needs external 4.7 kΩ pull-ups to 3.3 V.

**Cables:** only one lead came with the board. Buy single-ended (plug one end, bare wire the
other) **MX1.25 / Molex 51021-compatible 4-pin** leads. Measure pin 1 to pin 4 on P4 first:
≈3.75 mm confirms 1.25 mm pitch.

#### Step B wiring — decided, not yet connected

Supplied lead in P4, colours confirmed by the user:

| Wire | P4 pin | → FluidNC ESP32 |
| --- | --- | --- |
| Red | GND | GND |
| Yellow | 3.3V | **nothing — insulate** (never tie two 3.3 V rails) |
| Blue | IO17 (screen RX) | D17 (FluidNC TX) |
| Black | IO18 (screen TX) | D16 (FluidNC RX) |

Keep D33/D25 jumpered to GND. **Pass:** screen goes from NO LINK to linked, state Alarm;
resetting FluidNC shows link lost then recovered.

### Open items

| # | Item | Where |
| --- | --- | --- |
| 1 | ~~74HCT14 vs 74LVC14 for the MPG shifter~~ ✅ decided: **74LVC14 on 3.3 V**; BOM, drawings and code comments corrected. Still check the part that actually arrives | `docs/BOM.md` block G |
| 2 | ~~Input-conditioning pull-up placement~~ ✅ documented: pull-up on the sensor side of the 10 kΩ, clamp + 100 nF on the GPIO side | `docs/BOM.md` block E, `docs/WIRING-RevH.md` diagram 4 |
| 3 | Contactor coil voltage assumed 230 V AC in the wiring map | `docs/WIRING-RevH.md` diagram 5 |
| 4 | ~~Buck sizing justified by the old RGB panel~~ ✅ re-derived: ≈0.6–0.7 A load at 5 V, ≥2 A kept for ≈3× margin | `docs/BOM.md` block A |
| 5 | ~~Panel cutout unchecked~~ ✅ 120 × 70.2 mm from the Guition spec — still measure the board in hand before cutting | `docs/BOM.md` block F |
| 6 | ~~Pin table said "No MCP23017"~~ ✅ corrected: expander on its own I²C bus 1 (15/16) | `docs/DESIGN-PLAN-RevH.md` |
| 7 | ~~TB6600 common anode +5 V in one place~~ ✅ +3.3 V everywhere | `docs/DESIGN-PLAN-RevH.md` |
| 8 | Foot-switch release edge (dead-man retract) still unverified in FluidNC. Pedal **ordered 2026-09-13**; the edge behaviour can be tested before it arrives with a jumper on GPIO 13 | `firmware/README.md` |
| 9 | `steps_per_mm` 1066.67 is derived, not measured — needs a dial indicator | `firmware/README.md` |
| 10 | ~~Published wiring-map artifact still shows the old board~~ ✅ republished 2026-09-13 (version 2) | claude.ai artifact |

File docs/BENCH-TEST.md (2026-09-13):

# Bench-test plan

> **SUPERSEDED — this is the bring-up ladder for the single-board v1 firmware** (ESP32 DevKit + ILI9488,
> MCP23017 board-ID, DM542, `MotorControl`). **Do not follow it for the Rev H build.** What has actually
> been proven on the bench is in `docs/BRINGUP-LOG.md`; the gated Rev H test plan is the Verification
> section of `docs/DESIGN-PLAN-RevH.md` (and §8 of `docs/UART-PROTOCOL.md` for the link). Its safety
> contract and "one new piece of hardware per stage" discipline still apply. See `docs/SUPERSEDED.md`.

Incremental bring-up. Each stage must pass before adding the next piece of physical hardware. Do not skip ahead — every stage doubles as a fault-localisation tool for the next one. If stage N fails, the bug is in what stage N added, not what came before.

## Safety contract (applies to every stage)

- The router stays **unplugged from mains** until stage 7, with **no bit in the collet** until stage 8.
- A separately-wired E-stop on the 24 V rail (cuts stepper + relay simultaneously) must be within arm's reach from stage 5 onward. The firmware watchdog and soft-limit/endstop fault paths are software safeguards — not substitutes for a hardware cutoff.
- Keep `softMin` / `softMax` tight (e.g. ±5 mm around park) until stage 6 mechanics are validated. Plenty of time to widen them after.
- Never bypass `MotorControl::moveToMm()` in any test code added during bring-up; that single function is the soft-limit chokepoint (see `docs/ARCHITECTURE.md`).

## Tools

- USB cable + serial monitor at **115200 baud** (`pio device monitor` works).
- Multimeter for continuity / voltage checks before powering anything new.
- Logic analyser or scope (optional but useful at stages 4 and 5 for MPG / step pulse inspection).
- Digital calipers for stage 6 (brass-stamp offset calibration).

## Reading the firmware status

The boot banner is the first thing you should see:

```
=== RouterLift v1.1.0 ===
```

If the banner appears, the ESP32 booted and `Serial.begin(115200)` ran. Subsequent log lines tell you which modules failed `begin()`:

- `MCP23017 not found - degraded mode` — I²C did not detect the expander at `0x20`
- `Unknown function board (raw id=N)` — MCP responded but the 4-bit board-ID jumpers don't match any `BoardId` enum value
- `Function board: Router Lift` — full I/O working
- `MPG init failed`, `Display init failed`, `Touch init failed` — module-specific begin failures
- `Plunge ignored: spindle not at speed` / `Plunge ignored: router relay off` — runtime guard messages once stage 8 is reached

## Stage 1 — Bare ESP32

**Hardware**
- ESP32 DevKit V1 only. No MCP, no display, no stepper driver, no router. Powered from USB.

**Procedure**
1. Flash the firmware: `pio run -t upload`.
2. Open the serial monitor at 115200 baud.
3. Power-cycle.

**Pass criteria**
- Boot banner appears within ~1 s.
- Exactly one `MCP23017 not found - degraded mode` line is logged (expected — there is no MCP yet).
- No watchdog reboots (banner does not re-appear every 5 s).
- Top/bottom endstop messages are absent (no I/O expander to read them).

**If it fails**
- No banner → check USB power, board selection in `platformio.ini` (`board = esp32dev`), and that the serial monitor is at 115200.
- Reboot loop → most likely cause is the watchdog (`SafetyMon::begin()` adds the main task; if anything in `setup()` blocks > 5 s the WDT fires). Re-flash with `-DCORE_DEBUG_LEVEL=4` to get verbose ESP-IDF logs.

## Stage 2 — Add MCP23017

**Hardware added**
- MCP23017 wired to GPIO21 (SDA) / GPIO22 (SCL) with 4.7 kΩ pull-ups to 3.3 V. Address jumpers strapped for `0x20` (A0/A1/A2 to GND).
- Set the 4-bit function-board ID jumpers on Port B0..B3 to match `BoardId::ROUTER_LIFT` (= 1, so B0 to GND, B1..B3 floating high via internal pull-ups). Cross-reference `include/config.h::BoardId`.
- Endstop sensors and foot switch can be wired (per `docs/HARDWARE.md` MCP map) but do not need to be triggered yet.

**Procedure**
1. Power-cycle.
2. Watch the boot banner.
3. With the serial monitor open, manually trigger each endstop (wave a metal object past the inductive face) and the foot switch. Add a temporary debug print in `loop()` if you want to see live values:
   ```cpp
   static uint32_t lastDbg = 0;
   if (millis() - lastDbg > 250) {
       lastDbg = millis();
       Serial.printf("EB=%d ET=%d STAMP=%d FOOT=%d RATE=%u\n",
           IO.readEndstopBottom(), IO.readEndstopTop(),
           IO.readStampPickup(), IO.readFootSwitch(),
           IO.readRateMultiplier());
   }
   ```
   Remove this print before stage 5.

**Pass criteria**
- `Function board: Router Lift` appears (not `Unknown function board`).
- `MCP23017 not found - degraded mode` does **not** appear.
- Endstop / stamp / foot lines toggle 0↔1 on physical activation, with no chatter when idle.
- `RATE=` matches the rotary switch position (1, 10, 100; reads `0` if the wiper is between positions or the switch is unwired).

**If it fails**
- `MCP23017 not found` → check I²C wiring, pull-up presence, and that the I²C bus address is `0x20`. `pio device monitor` plus an I²C scanner sketch is a quick triage.
- `Unknown function board` → re-check the B0..B3 jumpers against `BoardId` in `include/config.h`. Each bit is active-LOW (jumper to GND = 1).
- Endstops chatter → the NPN open-collector lines need either an external pull-up to 3.3 V or interface optocouplers; do not rely on MCP internal pull-ups alone with long cable runs.

## Stage 3 — Add display + touch

**Hardware added**
- 3.5" ILI9488 SPI TFT with XPT2046 touch. SPI pins per the `platformio.ini` `build_flags` (SCK 18, MOSI 23, MISO 19, TFT_CS 15, DC 2, RST 4). Touch CS on GPIO 5, touch IRQ on GPIO 17 (polled in v1.1.0; the IRQ pin is wired but unused).
- Backlight to 5 V via a series resistor or driven from the TFT module's onboard LED pin per its datasheet.

**Procedure**
1. Power-cycle.
2. Confirm the main screen renders.
3. Tap the `MENU` bottom-bar button → tap `Calibration` → walk through `Motor`, `Motion`, `Limits`, `Sensors` rows. Confirm each tap registers and that selected rows highlight.
4. If hit points are off (tap registers a row above/below your finger), adjust `TS_X_MIN / TS_X_MAX / TS_Y_MIN / TS_Y_MAX` in `src/Touch.cpp` and re-flash. Default values fit a common panel but every batch is slightly different.

**Pass criteria**
- No `Display init failed` / `Touch init failed` lines.
- Status bar updates at roughly 20 Hz (counted by eye — `mm/pulse` readout updates smoothly).
- Tap accuracy across all corners of the 480×320 screen is within ~10 px after calibration.
- Returning to the main screen via the `Back` arrow works from every menu depth.

**If it fails**
- Display shows white/static → SPI wiring; re-check MISO is on 19, MOSI 23, SCK 18, and that `User_Setup.h` is **not** loaded (we use `USER_SETUP_LOADED=1` + build flags exclusively).
- Touch never registers → confirm `TOUCH_CS` on GPIO 5 and that the panel's touch controller shares the SPI bus correctly. The `TOUCH_CS pin not defined` warning during build is harmless (TFT_eSPI's own touch helpers are unused; we drive XPT2046 directly via `XPT2046_Touchscreen`).
- Touch hangs the UI on power-up with T_IRQ unwired → change `XPT2046_Touchscreen ts(Pins::TOUCH_CS, Pins::TOUCH_IRQ)` in `src/Touch.cpp` to `XPT2046_Touchscreen ts(Pins::TOUCH_CS)` (no IRQ arg).

## Stage 4 — Add MPG via opto-isolators

**Hardware added**
- 100 PPR 5 V MPG, level-shifted to ESP32 GPIO 32 (A) and GPIO 33 (B) via 2× PC817 opto-isolators per `docs/HARDWARE.md`. With opto-isolators the signal is inverted; `MPG::SIGNALS_INVERTED = true` in `include/config.h` is already wired for this.
- 3-position SP3T rate switch on MCP B4/B5/B6 if not already done in stage 2.

**Procedure**
1. Open the main screen.
2. Turn the wheel one full revolution clockwise slowly. The `mm/pulse` readout should multiply by the current band:
   - x1 → 0.001 mm/pulse base, ~0.001 mm/pulse at slow rotation
   - x10 → 0.010 mm/pulse base
   - x100 → 0.100 mm/pulse base
3. Spin briskly. Velocity scaling should kick in — `mm/pulse` rises toward `10×` the base step.
4. Reverse direction. Sign should flip without losing counts (the PCNT peripheral handles direction).
5. Cycle the rate switch through all three positions. The status bar label should change `x1` ↔ `x10` ↔ `x100`.

**Pass criteria**
- One full wheel turn = 100 net pulses on x1 base (verify by zeroing position and turning exactly one revolution in `Set Target` mode — target should change by 0.1 mm).
- Brisk rotation produces visibly larger per-pulse steps (gas-pedal feel).
- Idle wheel produces zero spurious pulses for >10 s.
- Reversing direction does not lose or gain counts (turn 100 pulses CW, then 100 pulses CCW; target returns to start within ±1 pulse).
- Rate switch reads correctly in all three positions; intermediate (between-detent) position reads `0` and the band does not change.

**If it fails**
- Pulses appear in the wrong direction → flip `MPG::SIGNALS_INVERTED`.
- Lost counts at high spin rate → either the opto LED current is too low (drop the series resistor from 330 Ω to 220 Ω) or the opto transistor pull-up is too high (drop the 10 kΩ to 4.7 kΩ). The PCNT peripheral itself does not lose counts; the analogue level shifter does.
- Rate switch reads `0` always → check that the switch common is wired to GND (not 3.3 V) and that the throws land on B4/B5/B6.

## Stage 5 — Add stepper driver (motor not yet mounted)

**Hardware added**
- DM542 stepper driver. PUL+/PUL- to GPIO 25 + GND. DIR+/DIR- to GPIO 26 + GND. ENA+/ENA- to GPIO 27 + GND. Driver microsteps set to give **1000 steps/rev** (DM542 SW dip table: 1000 = SW5/6/7/8 OFF/ON/ON/OFF).
- Stepper motor wired to A+/A-/B+/B- but **not yet bolted into the lift** — let it sit on the bench with the shaft free to spin. This isolates "motor moves" from "lift moves correctly".
- 24 V supply to driver power inputs. **Do not power the lift mechanics yet.**

**Procedure**
1. Tighten the soft limits to a narrow window for testing: open `MENU > Calibration > Limits` and set `softMin = -2 mm`, `softMax = 2 mm` (with the wheel; values persist via NVS after 2 s).
2. Power-cycle. The motor should energise briefly when `Motor.begin()` runs (audible click / holding torque).
3. On the main screen, tap the target field. Use the wheel to dial in `+1.0` mm. Tap `GO` (or whatever the explicit "move to target" path is in your build).
4. The motor should rotate smoothly to the new position. Reverse with `-1.0` mm.
5. **Soft-limit test:** dial a target of `+5.0` mm (outside `softMax`). The `moveToMm()` call should be rejected with no motion. The target field will jump back to a clamped value or the move will simply not start. No fault is generated for a rejected move — `moveToMm()` returns `false`.
6. **Endstop fault test:** physically wave a metal object past one of the inductive sensors (or short the sensor input to GND). The status should switch to a `FAULT` screen with `ENDSTOP_HIT` and the motor should be force-disabled. Acknowledge the fault via the UI to return to `IDLE`.

> **Note.** v1.1.0 does not yet ship a serial debug command parser, so the "command-line soft-limit test" mentioned in the handoff has to be done via the touch UI as described above. If you want a hard "try to move 1000 mm" stress test, add a one-shot test path behind a compile flag and remove it afterward.

**Pass criteria**
- Motion is smooth (no audible chatter, no missed steps when reversing direction at speed).
- A 10 mm round-trip ends at the same indicated position (within ±1 step).
- Soft-limit-violating targets are rejected silently (no motion, no fault — `moveToMm()` returned false).
- Endstop trigger forces a `FAULT_VIEW` screen and disables the driver. The relay (when wired in stage 7) also turns off as part of the fault path.

**If it fails**
- Motor stalls / chatters → speed/accel may be too high for the current microstep + voltage combination. Open `MENU > Calibration > Motion` and halve `Max speed` and `Accel`. NVS will remember the new values after 2 s idle.
- Reverses to wrong direction → `MENU > Calibration > Motor` → toggle `Dir invert`. (This is the v1.0.1 fix point — confirm the toggle now writes/reads the direction-invert flag, not the enable flag.)
- Position drift on round-trip → microstep mismatch between driver and `stepsPerRev` config. Re-check DM542 dip switches; the firmware default is 1000.

## Stage 6 — Mount motor on the lift

**Hardware added**
- Motor bolted to the lift body. Ball-screw spindle coupled to motor shaft via 698 RS bearing. Top + bottom inductive endstops wired and aimed at the moving carriage.
- Brass-stamp pickup wired but its position-offset will be calibrated in this stage.

**Procedure**
1. With soft limits still tight (from stage 5), hand-crank the lift to roughly mid-travel before powering on. This prevents the first homing pass from slamming into an endstop while you're testing.
2. Tap `MENU > Home`. The Homing module runs a two-stage seek: fast travel toward the bottom endstop, back off, slow re-approach for accuracy.
3. After homing completes, widen the soft limits to the real mechanical range via `MENU > Calibration > Limits`.
4. **Brass-stamp calibration:** measure the stamp-trigger-to-table distance with calipers (depress the stamp until the inductive sensor would trigger, measure to the table surface). Enter that value in `MENU > Calibration > Sensors > Stamp offset`.
5. Run `MENU > Zero` with the stamp positioned correctly. The carriage should descend slowly, trip on the stamp pickup, and report position = `stampOffsetMm`.
6. Test jog feel on all three rate bands:
   - x1: a single click of the wheel should produce a visibly small (~0.001 mm) movement that you can confirm only by watching the position readout.
   - x10: clearly visible per-click motion.
   - x100: rapid travel; the gas-pedal scaling should give ~1 mm per pulse when spun briskly.

**Pass criteria**
- Two-stage homing converges to a repeatable position (re-home three times in a row, observe the indicated zero stays within ±1 step).
- Zeroing places the carriage exactly `stampOffsetMm` above the table — confirm with a precision spacer or calipers.
- Jog feel is responsive across all three bands with no missed steps.
- No `HOMING_TIMEOUT` or `ZEROING_TIMEOUT` faults under nominal operation.

**If it fails**
- Homing times out → `Mech::DEFAULT_HOMING_SPEED_MM_S` may be too low for `Safety::HOMING_TIMEOUT_MS`, or the endstop is not in the travel path. Re-aim the inductive sensor and re-check `HOMING_TIMEOUT_MS` budget.
- Zeroing repeatability poor → stamp spring may be too stiff or the inductive sensor too far from the stamp face. Aim for the sensor to trigger within the first 0.2 mm of stamp deflection.
- Carriage hunts (oscillates) at end-of-travel → motion accel too low; let the firmware decelerate more gracefully by *raising* `Accel` slightly so the planned stop is reached before the soft-limit clamp kicks in.

## Stage 7 — Add SSR with router unplugged from mains

**Hardware added**
- Solid-state relay control input on GPIO 16. The router stays **unplugged from mains** — we are only verifying the relay clicks and the firmware enforces the startup delay.

**Procedure**
1. Tap `POWER ON` on the main screen. The SSR should click (audible / LED indicator).
2. Watch the status bar: it should show `WARMUP` for the duration of `RELAY_STARTUP_DELAY_MS` (default 2500 ms), then transition to `ON`.
3. Tap `POWER OFF`. SSR clicks off. Status bar returns to `off`.
4. **Plunge-gate test:** with the relay `WARMUP` (still in startup-delay window), press the foot switch. The serial log should print `Plunge ignored: spindle not at speed` and the carriage must **not** move.
5. With the relay fully `ON` (after the delay), press the foot switch. Confirm the plunge cycle starts (it will move toward the current target — the lift may move on the bench even without a router cutting, which is fine for this stage).

**Pass criteria**
- SSR responds to `POWER ON` / `POWER OFF` taps with no delay.
- `WARMUP` → `ON` transition timing matches `RELAY_STARTUP_DELAY_MS` (verify with a stopwatch — within ±100 ms is fine).
- Foot-switch plunge during `WARMUP` is correctly rejected (logged and no motion).
- Foot-switch plunge during `ON` starts a `PLUNGE` cycle; releasing the foot returns the lift to `Mech::DEFAULT_PARK_MM`.

**If it fails**
- SSR doesn't click → check that the SSR control input is rated for 3.3 V logic (most are 3-32 V DC, but verify). Check that GPIO 16 is wired through any required snubber/series resistor per the SSR datasheet.
- `WARMUP` never transitions to `ON` → check the `startupDelayMs_` persisted value via `MENU > Calibration > Sensors > Relay delay`. If it was accidentally set to a huge value, reset to 2500 ms.
- Plunge ignored even when `ON` → `Foot.justPressed()` is edge-triggered, not level. The press must be released and re-pressed cleanly; debounce is `Safety::BUTTON_DEBOUNCE_MS = 25 ms`.

## Stage 8 — Plug router in at lowest speed setting, no bit in collet

**Hardware added**
- Router plugged into the SSR-switched mains outlet. **Speed selector at its lowest setting.** **No bit in the collet.**

**Procedure**
1. Tap `POWER ON`. Confirm the router spools up to its (low) commanded speed during `WARMUP`.
2. After the relay reaches `ON`, set a small plunge target (e.g. 2 mm below park) via `MENU > Set Target`.
3. Press and hold the foot switch. The carriage should plunge to the target.
4. Release the foot switch. The carriage should return to `Mech::DEFAULT_PARK_MM`.
5. Repeat the plunge cycle 5–10 times to confirm reliability.
6. Tap `POWER OFF`. The SSR cuts; the router winds down.

**Pass criteria**
- Plunge starts only after `WARMUP → ON` (still rejected during warmup).
- Plunge and return motion is smooth at the configured `Max speed` / `Accel`.
- Releasing the foot switch always returns to park, including releases mid-plunge.
- No fault triggers occur during normal cycling.
- Emergency stop (the hardware 24 V cutoff from the safety contract): hit it during a plunge — the motor must stop instantly, the relay must cut, and the firmware should reboot cleanly with the relay defaulting to OFF on the next boot.

**If it fails**
- Router doesn't spool up during `WARMUP` → mechanical issue with the router or the SSR isn't actually passing mains current. Verify with the router selector on its lowest setting and double-check SSR load wiring.
- Plunge feels jerky → the router's vibration is not the issue here (no bit, low speed). Re-check stepper Accel / Max speed. Stepper resonance at certain speeds is common with low microstepping; bump microsteps to 1600 or 3200 (and update `stepsPerRev` accordingly).
- Random faults during cycling → likely electrical noise from the router on the 24 V rail. Add a snubber across the SSR load contacts and confirm the logic ground is star-pointed at the PSU (per `docs/HARDWARE.md` Power architecture).

## Stage 9 — Production cuts

**Pre-conditions**
- All stages 1–8 pass cleanly and have been re-verified within the last week.
- The hardware E-stop has been tested mid-plunge in stage 8.
- A bit is in the collet, mounted to spec, and you have routed test material that you are willing to scrap.

**Procedure**
- First cut should be a single shallow pass (e.g. 1 mm depth) in scrap material at the router's normal operating speed.
- Cycle the lift 10× more on the same scrap to confirm repeatability.
- Only then move to production stock.

**Pass criteria**
- Cut depth is consistent across 10 cycles (within ±0.05 mm — limited by mechanical stack, not firmware).
- No watchdog reboots, no fault triggers, no missed steps over an extended cutting session.
- The E-stop, when hit, still cleanly cuts power and reboots with the relay OFF.

## After bench-testing

- Restore production soft limits if you tightened them for stage 5 (`MENU > Calibration > Limits`).
- Remove any temporary `Serial.printf` debug prints added during stages 2 / 4.
- Tag a release (`v1.2.0` or whatever the next bump is) recording "bench-validated against physical lift" in the message.
- File any hardware quirks discovered (sensor positions, calibration offsets, dip-switch settings) into `docs/HARDWARE.md` so the next person doesn't rediscover them.

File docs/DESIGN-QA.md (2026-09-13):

# Design Q&A — refining Rev H

50 open questions. Answers feed `DESIGN-PLAN-RevH.md`, `SCHEMATIC-RevH.svg`, `BOM.md`
and the Rev H spec amendment. Answer in any order; leave blanks where you don't know yet.

Marked **[BLOCKING]** where the answer changes work already planned, **[BUY]** where it
affects what you order.

---

## Decisions recorded so far

| Q | Question | Answer |
| --- | --- | --- |
| — | Existing machine? | **None. Greenfield build.** The FXBB is reference only, never a retrofit target |
| — | Work the lift must do | **All four**: repeatable depth, grooves/dados/rebates, dovetails/joinery, keyhole slots |
| — | Mechanics approach | **Motorise a commercial manual lift body.** Host selected: **sauter Fräslift FML-P** — see `docs/MECHANICS-RevH.md`. JoinTech SmartLift inspected and **rejected** (nylon pinion drivetrain, known failure point, manufacturer defunct) |
| — | v1 scope | **Full spec as written** — all four canned cycles, full Z0 machinery |
| 17 | Motor idle current | **Stay energised always.** `$Stepper/IdleTime = 255`. ENA still wired to GPIO 14 so this stays changeable. Measure temperature at ACC-04 |
| 25 | Always-on-screen | **All four**: large height, Z0 validity, machine + router state, MPG scale + link status. Layout ~3:1 — dominant numeral over a slim status strip |
| 33 | Cycles in v1 | **All four.** Keyhole built last regardless — the only cycle where the cutter moves under power while engaged |
| 39 | Foot switch | **Hold to plunge, release to retract.** Dead-man behaviour, gated on relay ready |
| 43 | Link loss mid-cycle | **Feed hold immediately.** Z0 invalidated, re-home and re-probe required. No auto-resume |
| — | Physical buttons | **Six.** STOP on FluidNC's native `feed_hold_pin`; the other five on an MCP23017 I²C expander. LED on ROUTER only. All in the same panel as the display |
| 11 | Homing at power-up | **Unconditional.** No motion of any kind until homed, then no cycle until Z0 probed (MOT-04 + SAF-05 as written) |
| 14–16 | Motion rates | **Rapid 12 mm/s · plunge 2 mm/s · accel 100 mm/s²**; homing seek 10 mm/s, feed 1 mm/s. Conservative start — silent step loss under DEV-01 makes pushing rates a poor first move |
| 19 | Positive Z | **Bit rising = positive.** Home at bottom = machine zero. Display reads bit height above the table |
| 21 | Z0 reference | **Table top.** Depth = bit projection above the table, independent of stock thickness |
| 22 | Re-probe after bit change | **Mandatory, no override.** Every bit differs in length; a stale Z0 is simply wrong. *"Return to previous height" deliberately not included — addable later without weakening the rule* |
| 24 | Probe reads shorted | **Refuse to start, no override.** A shorted probe would set Z0 at whatever height the bit is at, giving a plausible but wrong depth |
| 26 | Presets | **Named, with an on-screen keyboard** (FW-08 as written). e.g. "6mm groove", "dovetail rough" |
| 27 | Target Set ceiling | **Long-press PRESET.** Keeps every height-memory function on one button |
| 34 | Pass advance | **Always require confirmation.** Lift holds after each pass until CYCLE START |
| 35 | Pass defaults | **Rough 2.0 mm, finish 0.3 mm.** Inside FW-03's ≤3 mm, at FW-04's default allowance |
| 41–42 | Diagnostics | **All four**: 20-event fault log, 30-min re-touch-off reminder, live diagnostics screen, runtime hours counter |
| 44 | Bit-change interlock | **Key switch in series with the contactor coil.** Key removable only when off — the contactor physically cannot pull in regardless of firmware |
| 8 | First switch type | **Mechanical roller lever.** Two wires, no 24 V near the GPIO, no PNP risk. Inductive fitted later as a proven upgrade |
| 13 | Top limit in bit-change | **Controlled stop, announced as normal.** "AT TOP — change bit", not a fault. The same switch in any other context stays a hard alarm |
| 18 | Microstepping | **Stay at 1/8.** Accuracy is full-step based (MOT-03), so finer buys smoothness not precision. Most timing headroom on an untested build |
| 23 | Probe feeds | **Find 5 mm/s, confirm 0.5 mm/s**, 1 mm retract between. The slow second touch delivers the repeatability |
| 28/29/32 | Display conventions | **mm, 2 decimals, English.** Matches ELE-08; English keeps status-strip labels short |
| 30/31 | Screen behaviour | **All four**: dim backlight when idle (never blank), splash with version + calibration date, link and FluidNC version at startup, persist last screen |
| 36 | Scribe pass | **On by default**, toggled per job |
| 37/38 | Cycle build order | **Standard → bit-change → dovetail → keyhole.** Dependency order; keyhole last as the only cycle cutting under power |
| 45 | Build sequence | **Full bench test before mounting.** Steps 1–6 on the desk, motor unmounted, router unplugged |
| 46/47 | Equipment | **All four**: dial indicator 0.01 mm, DIN rail enclosure, multimeter, current-limited bench PSU |
| 49 | First job | **A through dado or groove.** Exercises the full standard cycle and is directly measurable with calipers |
| 50 | Spec Rev H timing | **After bench testing**, so Rev H records what was verified rather than intended |

### Settled configuration values

Everything below goes straight into `firmware/config.yaml` or the HMI defaults. Only
`steps_per_mm` remains provisional.

| Parameter | Value | Source |
| --- | --- | --- |
| `steps_per_mm` | **1066.67 — PROVISIONAL** | 1/8 µstep at the FML-P's published 1.5 mm lead — derived, not measured. **Measure on the real lift** (was 800 at an assumed 2 mm lead before the FML-P was chosen) |
| `max_travel_mm` | 65 | FML-P travel; conflicts with MEC-01 ≥75 mm (open) |
| TB6600 current | 1.0–1.4 A/phase | Motor oversized — see Consequences below |
| Positive direction | Bit rising; home at bottom = machine zero | Q19 |
| Rapid | 12 mm/s (720 mm/min) | Q14–16 |
| Plunge | 2 mm/s (120 mm/min) | Q14–16 |
| Acceleration | 100 mm/s² | Q14–16 |
| Homing seek / feed | 10 mm/s / 1 mm/s | Q14–16 |
| Probe find / confirm | 5 mm/s / 0.5 mm/s, 1 mm retract | Q23 |
| `$Stepper/IdleTime` | 255 (never disable) | Q17 |
| Microstepping | 1/8 — 1600 pulse/rev | Q18 |
| Rough depth / finish allowance | 2.0 mm / 0.3 mm | Q35 |
| Scribe pass | On, 0.3 mm | Q36 |
| Z0 reference | Table top | Q21 |
| Units / decimals | mm, 2 dp | Q28–29 |

### Behavioural rules settled

- **Nothing moves until homed; no cycle until Z0 is probed.** No exceptions, no override (Q11).
- **Every bit change forces a re-probe.** No override (Q22).
- **A shorted probe refuses the cycle.** No override (Q24).
- **Each pass holds until CYCLE START.** No auto-advance (Q34).
- **Link loss is an immediate feed hold**, Z0 invalidated, re-home and re-probe (Q43).
- **Foot switch is dead-man**: hold to plunge, release retracts (Q39).

Note the pattern — five of these deliberately have no override. That is a coherent stance for a
machine with no stall detection, where a wrong reference produces a plausible-looking cut at the
wrong depth rather than an obvious failure.

### Worked example — the pass scheduler with these defaults

A 10 mm groove, scribe on, rough 2.0 mm, finish 0.3 mm:

| Pass | Depth | Note |
| --- | --- | --- |
| scribe | 0.30 mm | FW-05, clean shoulder in ply or veneer |
| rough 1 | 2.72 mm | equalised across 4 roughs to reach 9.70 |
| rough 2 | 5.13 mm | |
| rough 3 | 7.55 mm | |
| finish | 10.00 mm | FW-04 allowance, full depth |

Each pass holds at depth until CYCLE START is pressed (Q34).

### New hardware consequence

The **key switch** (Q44) is a new BOM line and changes schematic block A: it goes in series with
the contactor coil, between the relay contact and A2. With the key out the router cannot be
energised no matter what FluidNC or the HMI does — a genuine hardware interlock satisfying SAF-02,
rather than a software promise.

### Physical control panel (new — supersedes parts of Q25/Q27)

Six buttons with FXBB-style short/long-press doubling, giving twelve functions.

**Split across both boards, deliberately.** FluidNC's native control pins act with no HMI
involvement whatsoever, so **STOP still halts motion if the S3 has crashed or the UART has
dropped**. The other five depend on HMI state — PRESET reads NVS on the S3, ZERO orchestrates the
probe and Z0 validity, BIT CHANGE drives an HMI state machine — so they cannot move to FluidNC
without the fork problem.

| # | Button | Board | Short press | Long press |
| --- | --- | --- | --- | --- |
| 1 | **STOP** | **FluidNC GPIO 21** → `feed_hold_pin` | Feed hold — halt motion, router stays on | Soft reset (`0x18`) |
| 2 | **CYCLE START** | MCP23017 A0 | Start cycle / advance to next pass | — |
| 3 | **ROUTER** | MCP23017 A1 | Toggle router power (`M3`/`M5`) — **LED lit = live, blinking = warming** | — |
| 4 | **BIT CHANGE** | MCP23017 A2 | Rapid to top, lock out motion | Exit, forcing re-probe |
| 5 | **ZERO** | MCP23017 A3 | Probe touch-off (`G38.2`) | Set zero here, no probe |
| 6 | **PRESET** | MCP23017 A4 | Recall active preset height | Save current height to it |
| — | rough/fine switch | MCP23017 A5 | MPG scale (ELE-09) | — |
| — | ROUTER LED | MCP23017 B0 | lit = live, blinking = warming | — |

MCP23017 at **0x20** on its own I²C bus (SDA GPIO 15 / SCL GPIO 16, connector P3, external 4.7 kΩ
pull-ups) — the GT911 touch bus is not brought out to any connector. Internal pull-ups, buttons to
GND, polled at 20 Hz with debounce. Ten I/O spare for later.

⚠️ **STOP is a feed hold, not an E-stop.** The E-stop remains the mains-rated mushroom that kills
the contactor. They must be physically unmistakable — E-stop as a red mushroom on yellow, STOP as
a flush round button, mounted well apart. Two red mushrooms with different behaviours is a
dangerous panel.

The touchscreen keeps only genuine second-level work: cycle configuration, preset management,
calibration, diagnostics, fault detail.
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

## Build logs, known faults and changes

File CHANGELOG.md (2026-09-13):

# Changelog

All notable changes to this project will be documented in this file.

This project adheres to [Semantic Versioning](https://semver.org/spec/v2.0.0.html).

## [Unreleased] — HMI board correction

Bench bring-up on 2026-09-13 showed the panel in hand is a **Guition
JC4827W543C**, not the Sunton ESP32-4827S043 that Rev H recorded. Spec Annex
B.10 was right; Rev H's "correction" of it was mistaken.

### Fixed

- HMI targets the JC4827W543C (XH-S3E N4R8 module): NV3041A panel over 4-bit
  QSPI (CS 45, SCK 47, D0–D3 21/48/40/39), IPS colour inversion, backlight on
  GPIO 1
- GT911 touch on the board's own I²C bus, SDA 8 / SCL 4, INT 3, RST 38. Both
  touch axes are flipped in firmware to match the panel at rotation 0
- MCP23017 button expander moved to its own I²C bus on GPIO 15 SDA / 16 SCL
  (connector P3), with external 4.7 kΩ pull-ups — the touch bus reaches no
  connector
- MPG A/B moved from GPIO 11/12 to 6/7 (connector P3); 11/12 are TF-card lines
  on this board
- `huge_app.csv` partitions — the stock 8 MB table boot-looped on 4 MB flash
- `memory_type = qio_opi` confirmed: PSRAM is octal, quad fails the ID read
- HMI now polls FluidNC with `?` every 100 ms (`LinkCfg::POLL_MS`, previously
  unused). FluidNC's `report_interval_ms` only reports on change, so an idle
  machine in Alarm sent nothing and the panel showed NO LINK with correct
  wiring (`91aea06`)
- MPG level shifter corrected to a **74LVC14 on 3.3 V**, two stages per
  channel, non-inverting (`SIGNALS_INVERTED = false`). The 74HCT14 recorded
  earlier needs a 5 V supply and would drive 5 V outputs into the ESP32-S3
- FluidNC spindle section key is `Relay:` — `relay_spindle:` is silently
  ignored; no comments or quotes on YAML section-header lines

### Verified on the bench (2026-09-13)

- FluidNC v4.1.0 (esp32-wifi) on a 30-pin ESP32-WROOM-32 devkit:
  `config.yaml` parses; `uart1` / `uart_channel1` keys work; limits read
  NC-correct (unwired → Hard Limit, jumpered → `ALARM:14` Unhomed); joins WiFi
  as `routerlift.local`, falls back to AP `FluidNC`
- Step B, UART link: link comes up, link loss sends feed hold and invalidates
  Z0, link recovers on its own and Z0 stays invalid until re-probed
- A stuck positive-limit reading traced to a poor-contact bench jumper, not
  GPIO 25

### Added

- `hmi-diag` PlatformIO environment for board bring-up
- `docs/BRINGUP-LOG.md` — bench bring-up log, newest first, with a resume
  checklist (`f65baf4`)
- FluidNC telnet console on port 23 (`routerlift.local:23`) documented as the
  console when USB serial is unavailable (`3f77855`); `$Limits` shows live
  input state, exit with `!`
- Input-conditioning pull-up placement documented: the 10 kΩ goes on the
  sensor side, or a closed switch only pulls the GPIO to ~2.2 V

## [Unreleased] — Rev H split architecture

The single-ESP32 design is superseded. Motion moves to stock FluidNC on a
classic ESP32; a 4.3" ESP32-S3 touch panel becomes the operator interface and
GRBL sender. FluidNC does not run on the S3, and the S3 cannot carry the full
machine pin budget — hence two boards.

**Nothing has been cut on this machine yet.** `steps_per_mm` is a placeholder
and the lift body is not bought.

### Added

- `firmware/config.yaml` — the complete FluidNC machine definition: axis,
  homing, soft limits, probe, `relay_spindle`, `macro0_pin`. No C++; the
  motion board runs an unmodified FluidNC binary (`298aabf`)
- `docs/UART-PROTOCOL.md` — HMI ↔ FluidNC command vocabulary, with `Link` as
  the single writer so the vocabulary stays exhaustive (`0995735`)
- `hmi/` — PlatformIO ESP32-S3 project for the ESP32-4827S043 panel
  - Increment 1: `Link` GRBL sender with one-command-in-flight window,
    `Wheel` PCNT quadrature decode with look-ahead clamp and
    cancel-on-reversal, `Buttons` on MCP23017 with short/long press (`e450644`)
  - Increment 2: Arduino_GFX RGB panel, GT911 touch, LVGL 8.4, main
    screen (`39c20b0`)
  - Increment 3: `Zero` two-touch probe sequencing and Z0 validity,
    `Store` named presets in NVS (`efb3d2c`)
- Rev H design set — four diagrams, BOM, design plan and Q&A (`e1b3230`),
  42 of 50 Q&A answers recorded (`9e16441`), Word design review
  document (`e80815e`)
- `docs/Router_Lift_Requirement_Specification_RevG.md` and the as-built
  wiring diagram (`d8e507a`)
- Mechanics Rev A — lift body selection and stepper drive design (`383e996`),
  workshop survey checklist (`e3b9cbf`)
- Lift body investigation: Sauter confirms the FML-P drives from the lower
  hex (`9189bf2`), full-size alternatives surveyed (`43da575`), the Wnew
  manual rules that lift out as shipped (`cf2d94d`), and the four candidates
  compared (`01c7596`, `f858ef2`)

### Changed

- **Soft limits are commissioning-only.** They live in `config.yaml` and are
  no longer operator-editable. Per-job ceilings come from presets and a
  teachable travel ceiling, both of which can only ever be *narrower* than the
  commissioned envelope
- **Rate switch is two positions (rough/fine)**, not the x1/x10/x100 bands
- **The HMI has no motion authority.** Homing, limits and probing are enforced
  by FluidNC. A bug in our firmware can produce a wrong depth, never an
  unsafe move
- Display board is the ESP32-4827S043 (RGB parallel), departing from spec
  Annex B.10's JC4827W543C/NV3041A — B.10 is wrong and is corrected in Rev H
- `README.md` rewritten for the two-board design (`1d0f235`)

### Removed

- Bespoke motion, homing, safety, relay and foot-switch firmware — all now
  native FluidNC behaviour. Reimplementing the homing state machine would be
  actively harmful
- ILI9488 TFT, XPT2046 touch controller, FastAccelStepper
- Function-board 4-bit ID. The MCP23017 remains in the HMI as the panel-button
  expander, but no longer identifies a board

### Deprecated

- The v1.x firmware moved to `legacy/`, kept as a porting reference and
  deliberately not built — no environment points at it (`01511d2`). The
  original root layout is recoverable at tag `v1.1.0-bespoke`

### Known issues

- `steps_per_mm: 800` and `MpgCfg::SCREW_LEAD_MM = 2.0` are placeholders
  assuming a 2 mm lead. Until measured against a dial indicator every depth is
  wrong by an unknown factor, invisibly — there is no stall detection to
  contradict a bad number
- The foot switch needs both press and release edges for dead-man behaviour.
  Whether `macro0_pin` fires on release is unverified; the mirrored-input plan
  in `firmware/README.md` is not yet proven
- Seven `config.yaml` items still to verify against the installed FluidNC
  release
- `docs/ARCHITECTURE.md` still describes the legacy module map
- HMI increments 4 (cycles) and 5 (fault log, diagnostics) not started

---

## [1.1.0-bespoke] - 2026-09-02

Tag only. The final state of the single-ESP32 firmware before the RevG pivot,
preserving the original root layout with `src/` and `include/`.

---

## [1.1.0] - 2026-05-25

### Added

- `Settings` module — NVS-persisted calibration under namespace `rl-cfg`, so
  motion, limit, relay and direction values survive a power cycle instead of
  resetting to defaults on boot. Writes are debounced 2 s to reduce NVS
  wear on rapid wheel turns (`ef13b68`)
- `docs/BENCH-TEST.md` — staged bring-up plan, each step passing before the
  next piece of hardware is fitted
- `docs/SCHEMATIC.svg` — wiring schematic (`20e6411`)

### Fixed

- First clean compile of the v1.0 firmware (`dd7aca4`)

---

## [1.0.1] - 2026-05-25

### Fixed

- Dir-invert calibration row read and wrote the motor-enable flag instead of
  the direction-inversion flag. Adds `MotorControl::dirInverted()` and uses it
  in `Menu` and `Display` (`307f81f`)

---

## [1.0.0] - 2026-05-24

Initial release.

### Added

- ESP32 firmware foundation built on PlatformIO + Arduino framework
- Motion control via FastAccelStepper with mm-based API and soft limits
- CNC-style manual pulse generator (MPG) input
  - 100 PPR full-quadrature decode via PCNT peripheral
  - 3-position rate switch (x1 / x10 / x100) for step-size band
  - Velocity-aware scaling within each band
- Touch UI on 3.5" ILI9488 + XPT2046
  - Bottom-bar buttons (MENU / PARK / POWER) on main screen
  - Hierarchical menu with BACK button
  - In-place calibration editing (tap row → edit with MPG → tap to commit)
- Six NVS-backed height presets
- Two-stage homing routine (fast seek + slow re-approach)
- Brass-stamp tool zeroing with offset compensation
- Solid-state relay control with configurable startup delay
- Foot switch plunge cycle (target → park)
- Dual-board architecture: 4-bit board ID via MCP23017 Port B
- Hardware watchdog and centralised fault handling
- ILI9488 display with sprite double-buffering

### Documentation

- `README.md` — quick start and tuning checklist
- `docs/HARDWARE.md` — BOM, pin map, level-shifter circuits
- `docs/ARCHITECTURE.md` — module map, state machine, safety design
- `docs/UX.md` — input model, screen-by-screen reference
- `CONTRIBUTING.md` — code style and PR guidelines

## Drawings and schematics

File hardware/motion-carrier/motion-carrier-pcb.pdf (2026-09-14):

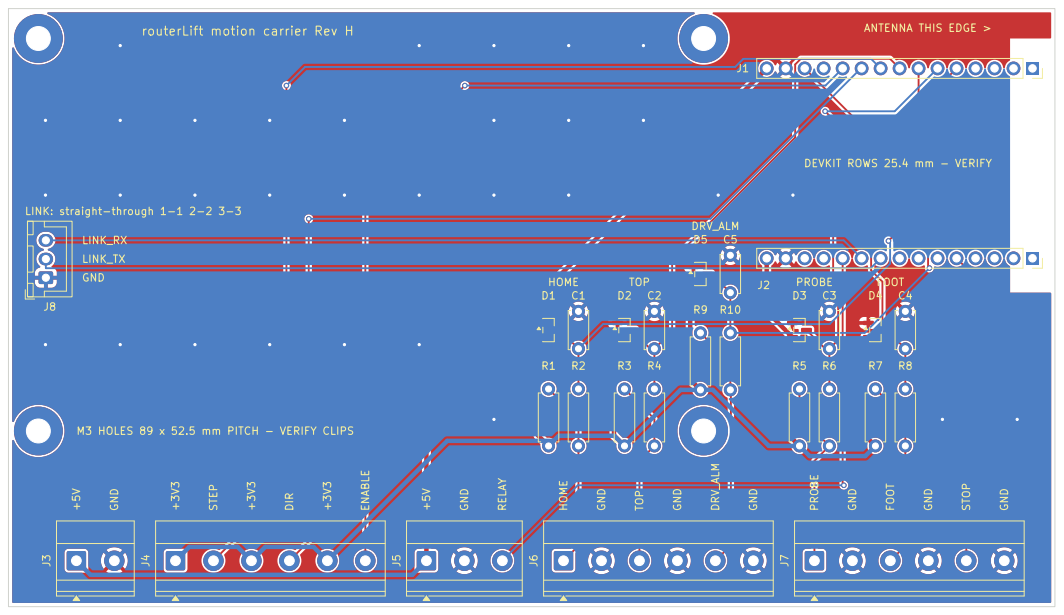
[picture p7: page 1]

routerLift motion carrier Rev H

LINK: straight-through 1-1 2-2 3-3 M3 HOLES 89 x 52.5 mm PITCH - VERIFY CLIPS

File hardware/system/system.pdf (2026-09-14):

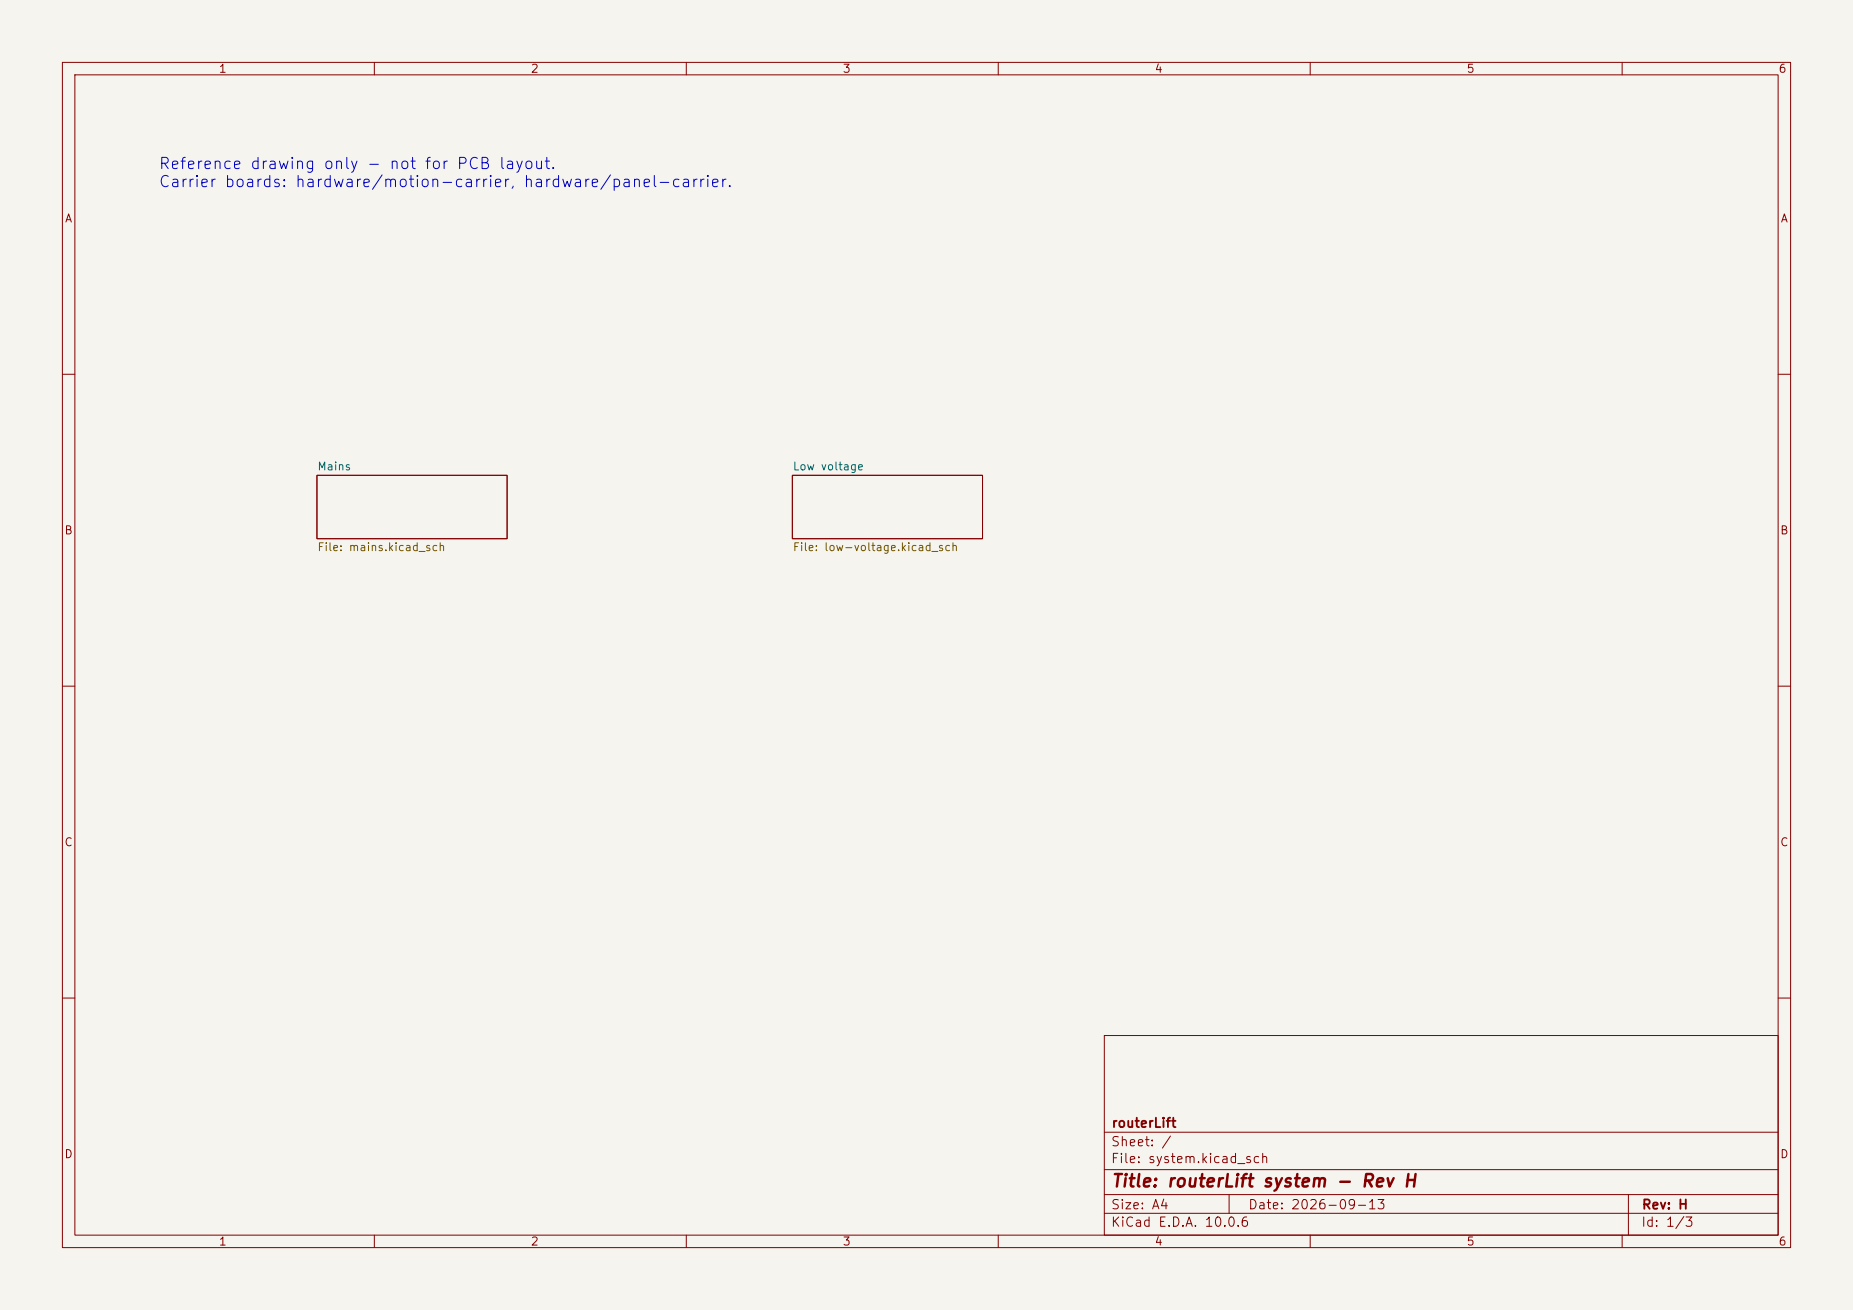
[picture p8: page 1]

Reference drawing only - not for PCB layout.
Carrier boards: hardware/motion-carrier, hardware/panel-carrier.

routerLift
Sheet: /
File: system.kicad_sch
Title: routerLift system - Rev H

Size: A4 | Rev: H
KiCad E.D.A. 10.0.6 | Id: 1/3

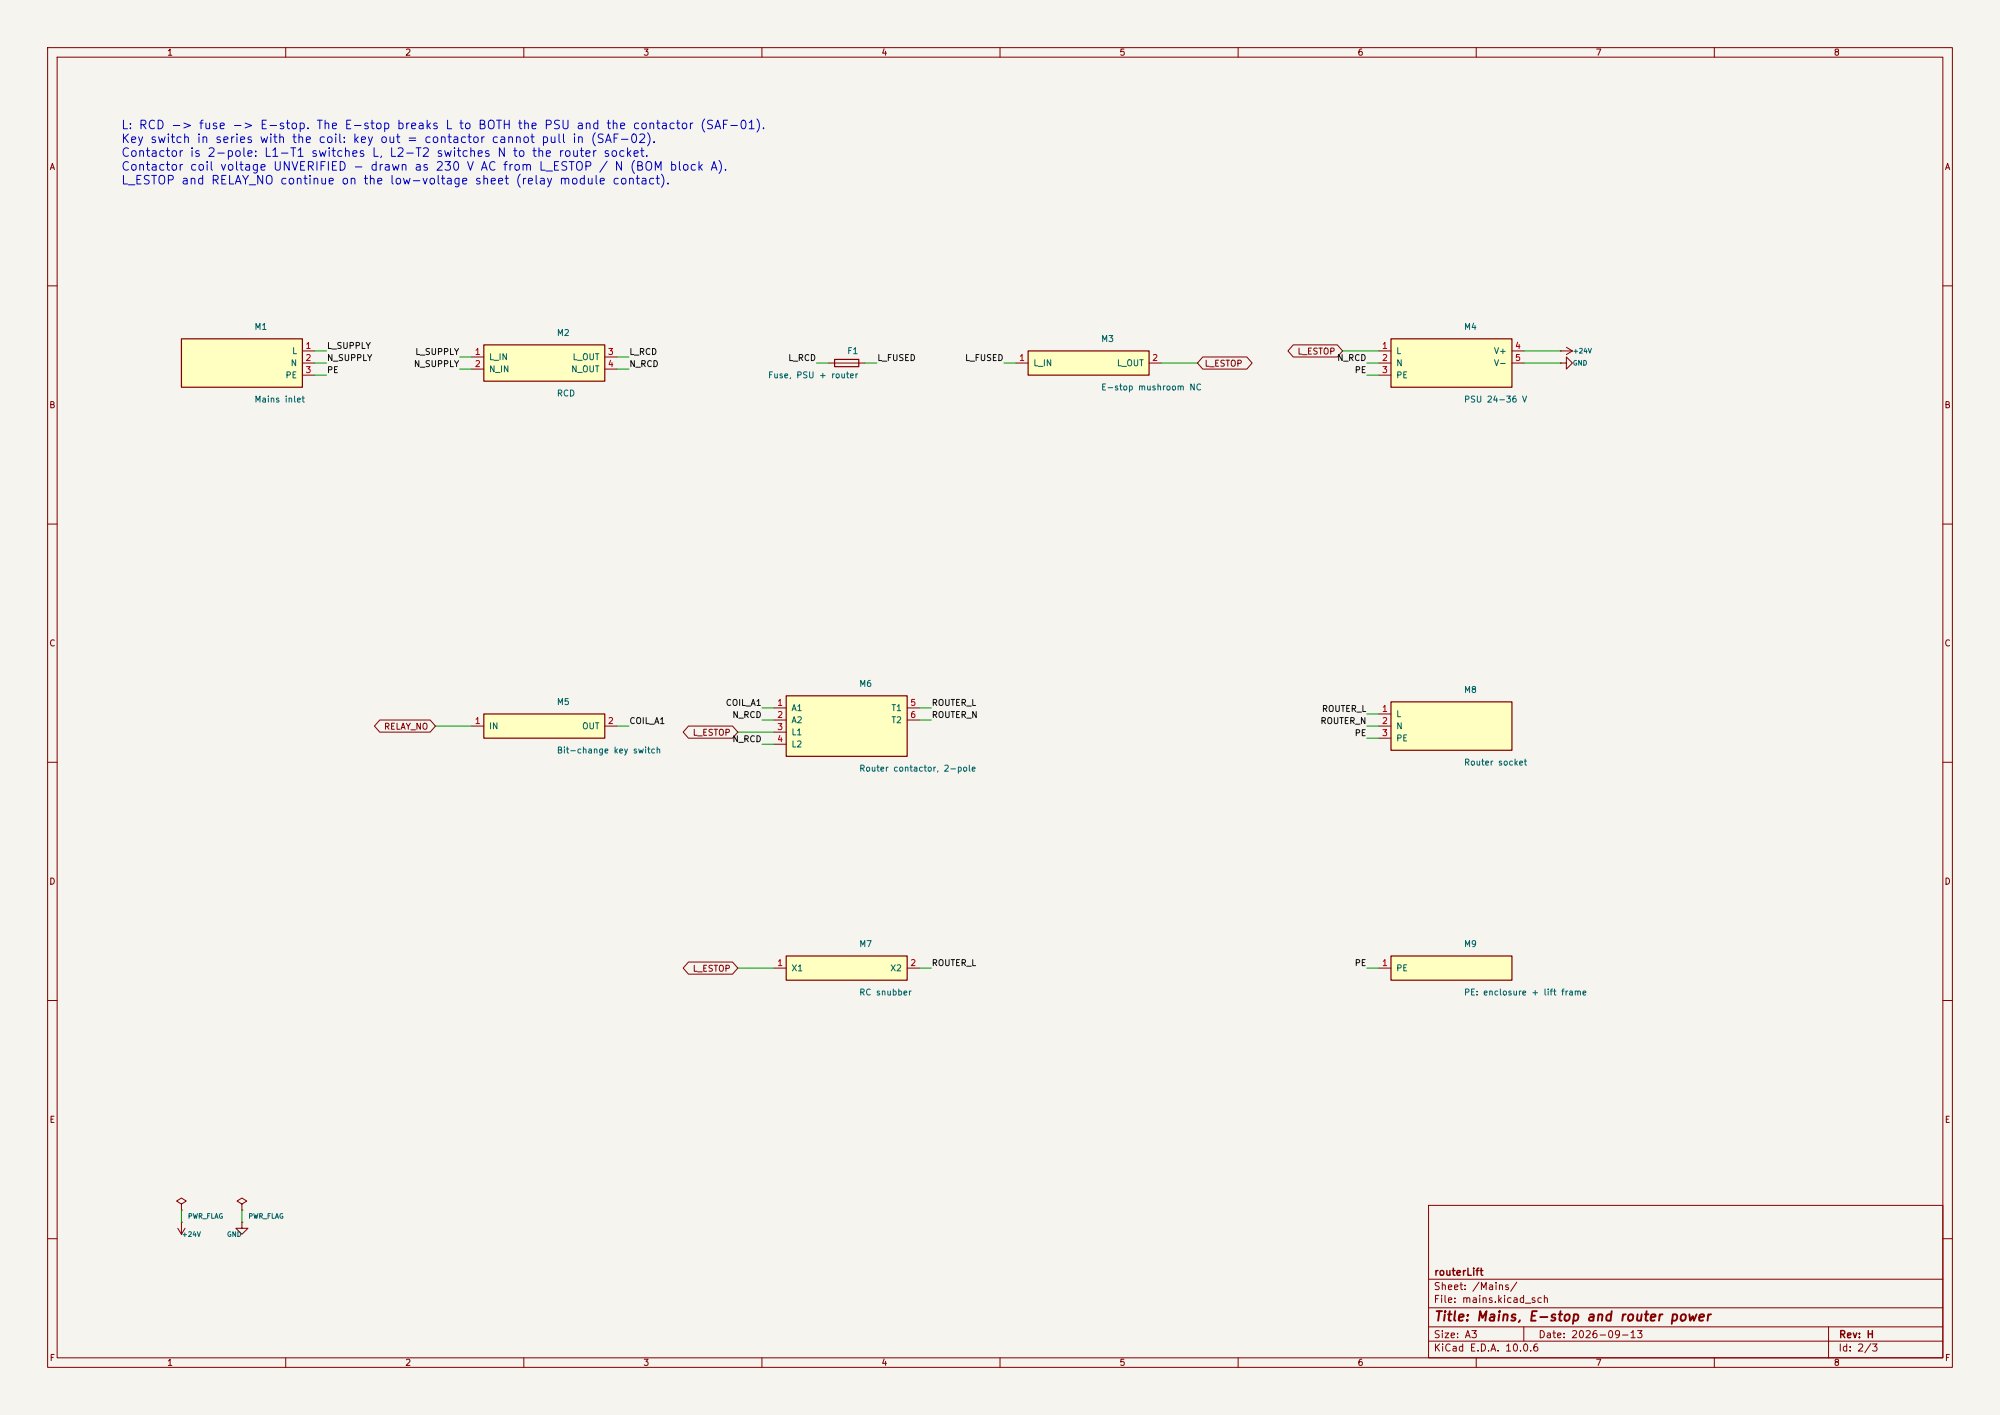
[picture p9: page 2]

Key switch in series with the coil: key out = contactor cannot pull in (SAF-02).
Contactor is 2-pole: L1-T1 switches L, L2-T2 switches N to the router socket.
Contactor coil voltage UNVERIFIED - drawn as 230 V AC from L_ESTOP / N (BOM block A).
L_ESTOP and RELAY_NO continue on the low-voltage sheet (relay module contact).

Sheet: /Mains/
File: mains.kicad_sch
Title: Mains, E-stop and router power

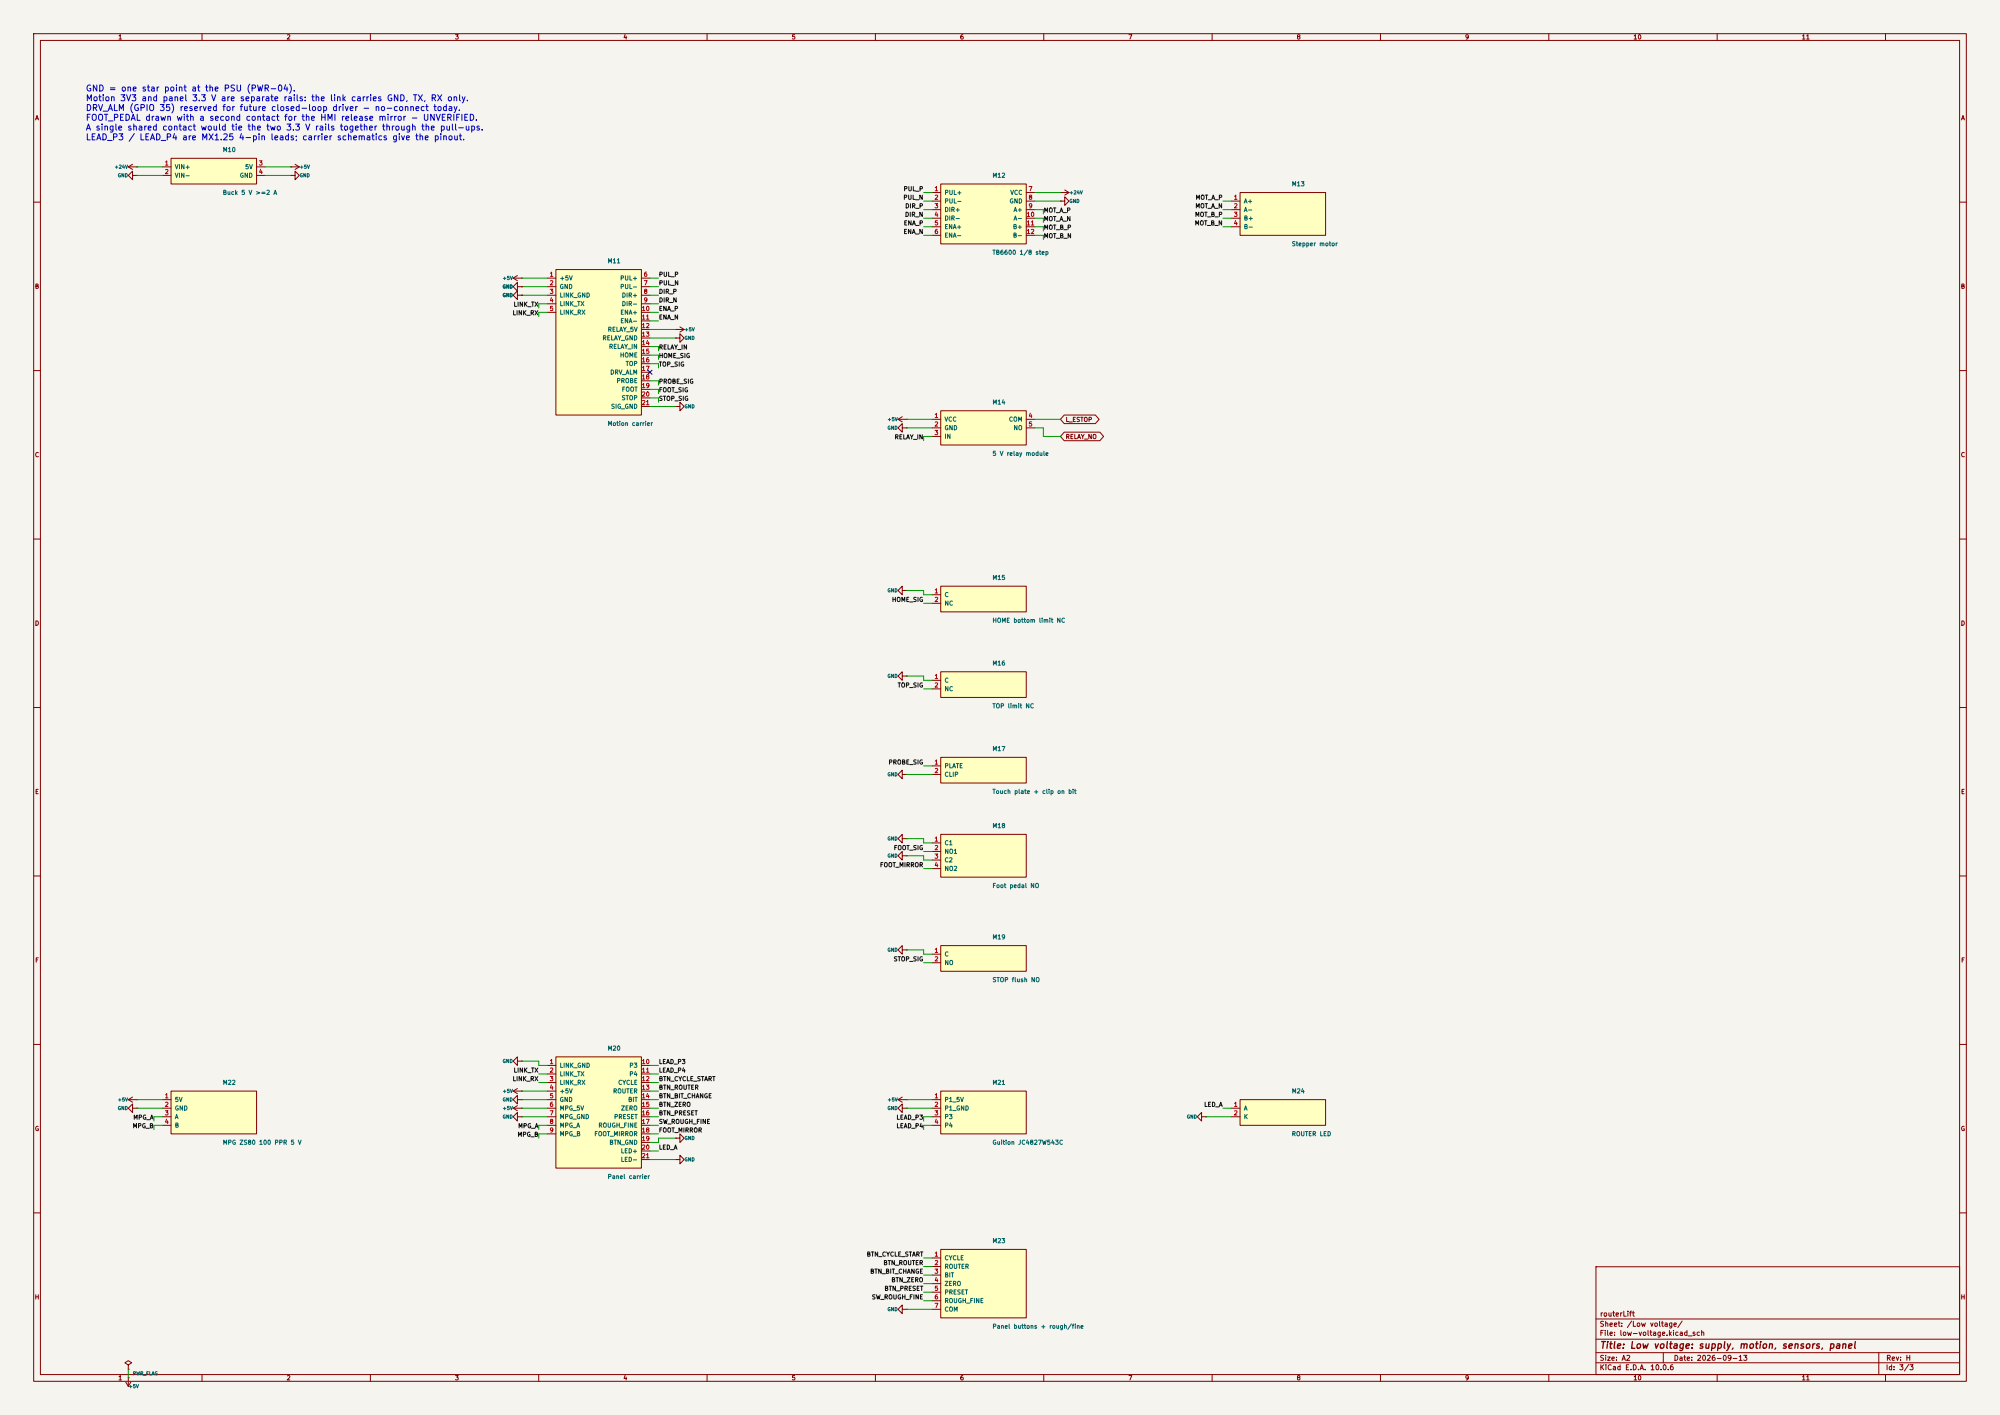
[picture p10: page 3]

GND = one star point at the PSU (PWR-04).
Motion 3V3 and panel 3.3 V are separate rails: the link carries GND, TX, RX only.
DRV_ALM (GPIO 35) reserved for future closed-loop driver - no-connect today.
FOOT_PEDAL drawn with a second contact for the HMI release mirror - UNVERIFIED.
A single shared contact would tie the two 3.3 V rails together through the pull-ups.

routerLift
Sheet: /Low voltage/
File: low-voltage.kicad_sch
Title: Low voltage: supply, motion, sensors, panel

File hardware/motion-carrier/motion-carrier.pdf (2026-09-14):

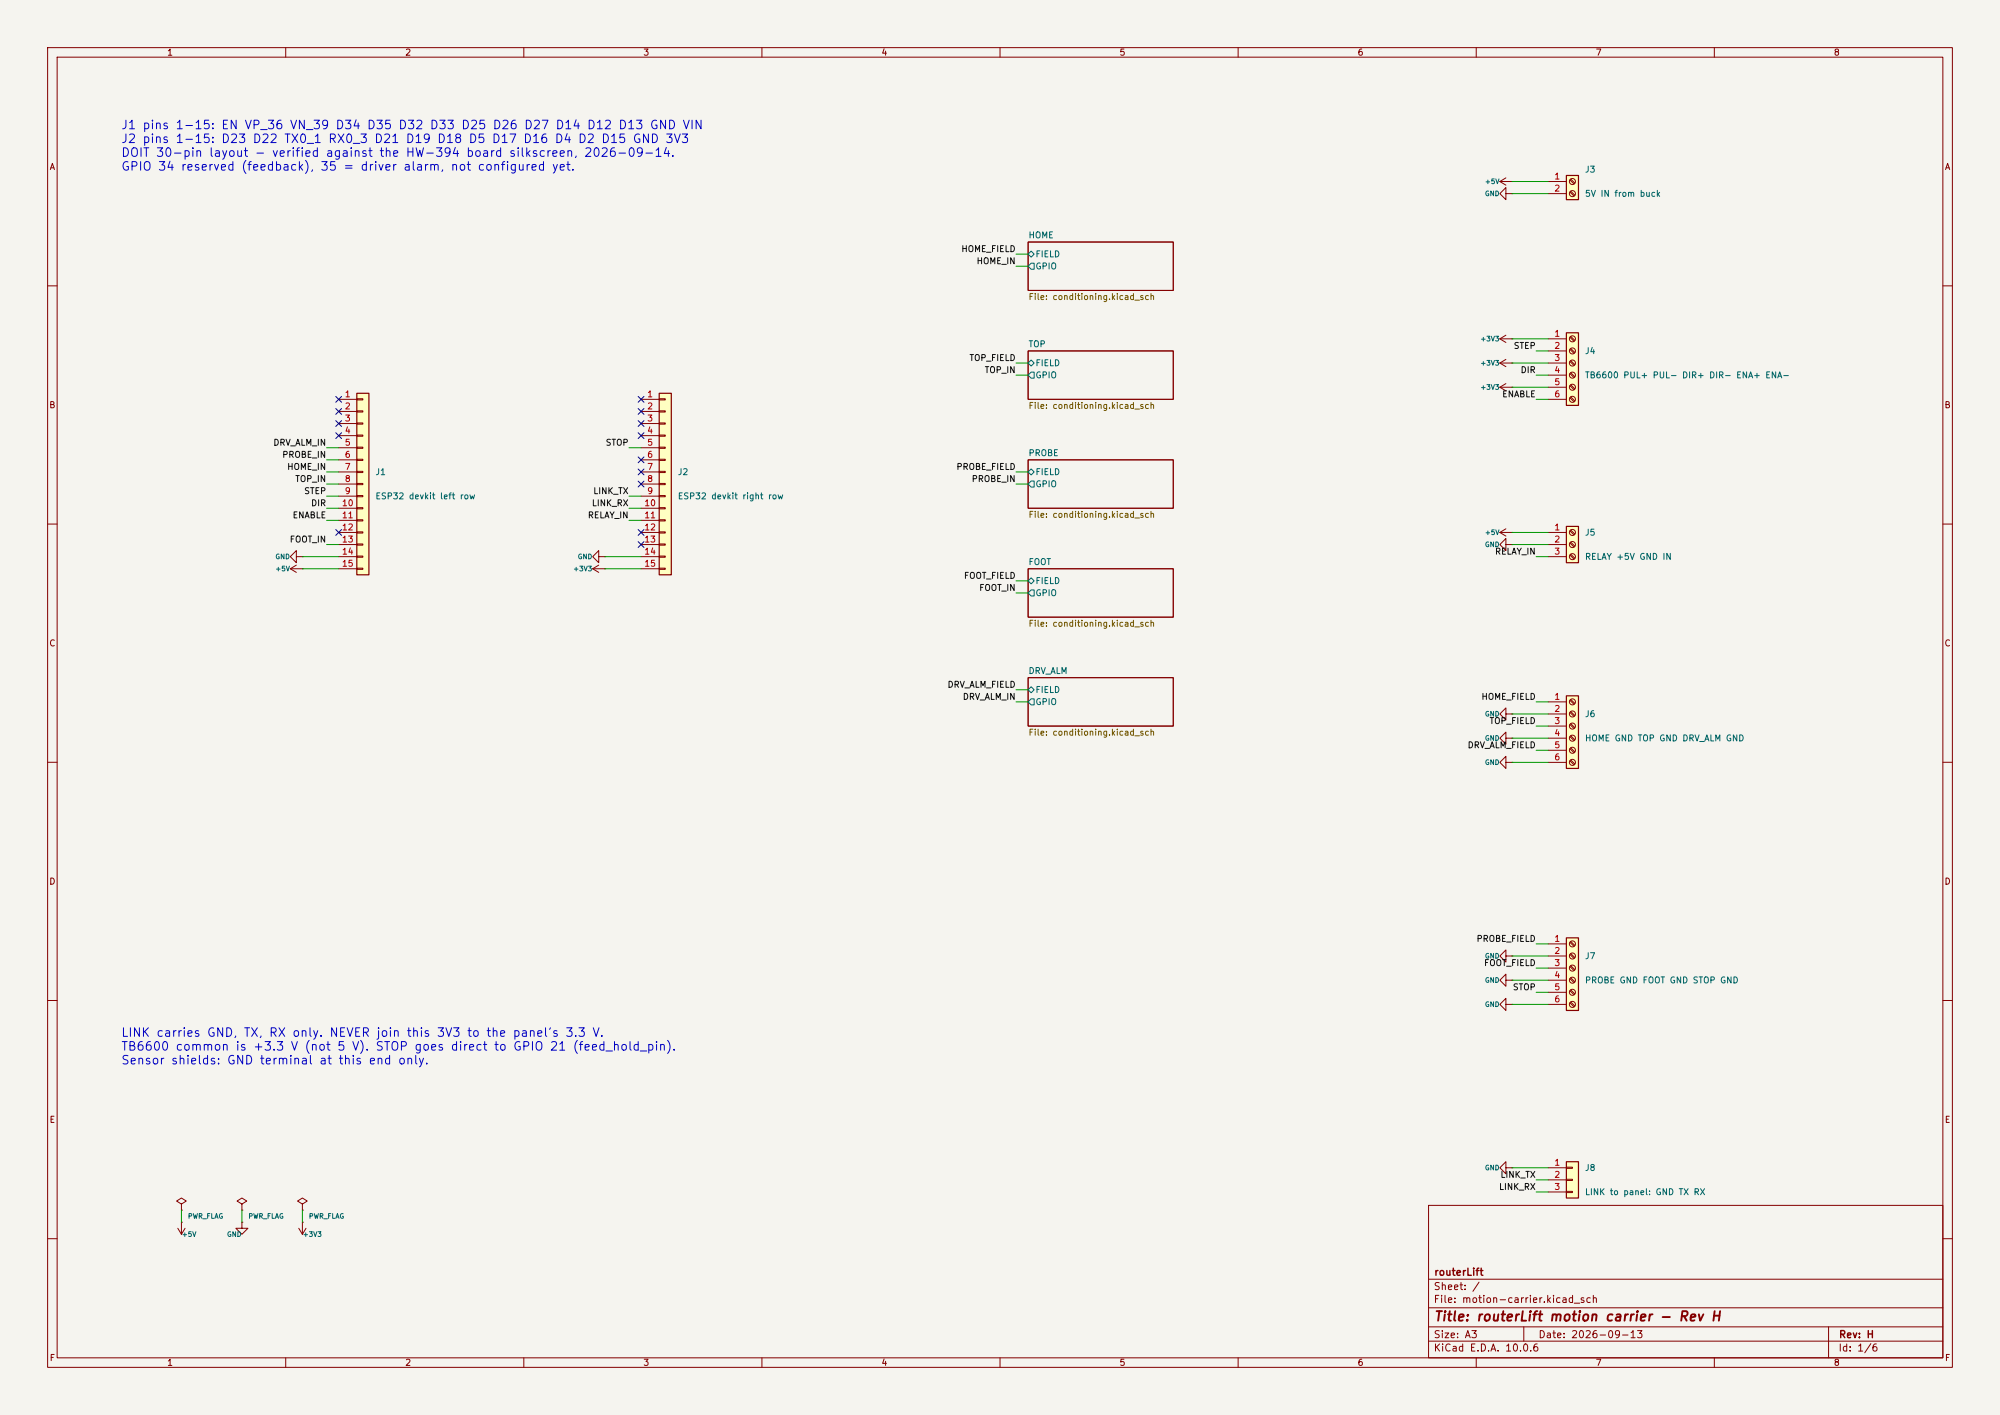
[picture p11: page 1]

J1 pins 1-15: EN VP_36 VN_39 D34 D35 D32 D33 D25 D26 D27 D14 D12 D13 GND VIN
J2 pins 1-15: D23 D22 TX0_1 RX0_3 D21 D19 D18 D5 D17 D16 D4 D2 D15 GND 3V3
DOIT 30-pin layout - verified against the HW-394 board silkscreen, 2026-09-14.
GPIO 34 reserved (feedback), 35 = driver alarm, not configured yet.

TB6600 PUL+ PUL- DIR+ DIR- ENA+ ENA-

PROBE_IN LINK carries GND, TX, RX only. NEVER join this 3V3 to the panel's 3.3 V.

J6HOME GND TOP GND DRV_ALM GND

J7PROBE GND FOOT GND STOP GND

TB6600 common is +3.3 V (not 5 V). STOP goes direct to GPIO 21 (feed_hold_pin).
Sensor shields: GND terminal at this end only.

LINK to panel: GND TX RX

routerLift
Sheet: /
File: motion-carrier.kicad_sch
Title: routerLift motion carrier - Rev H

Size: A3 | Rev: H | F Date: 2026-09-13
KiCad E.D.A. 10.0.6 | Id: 1/6

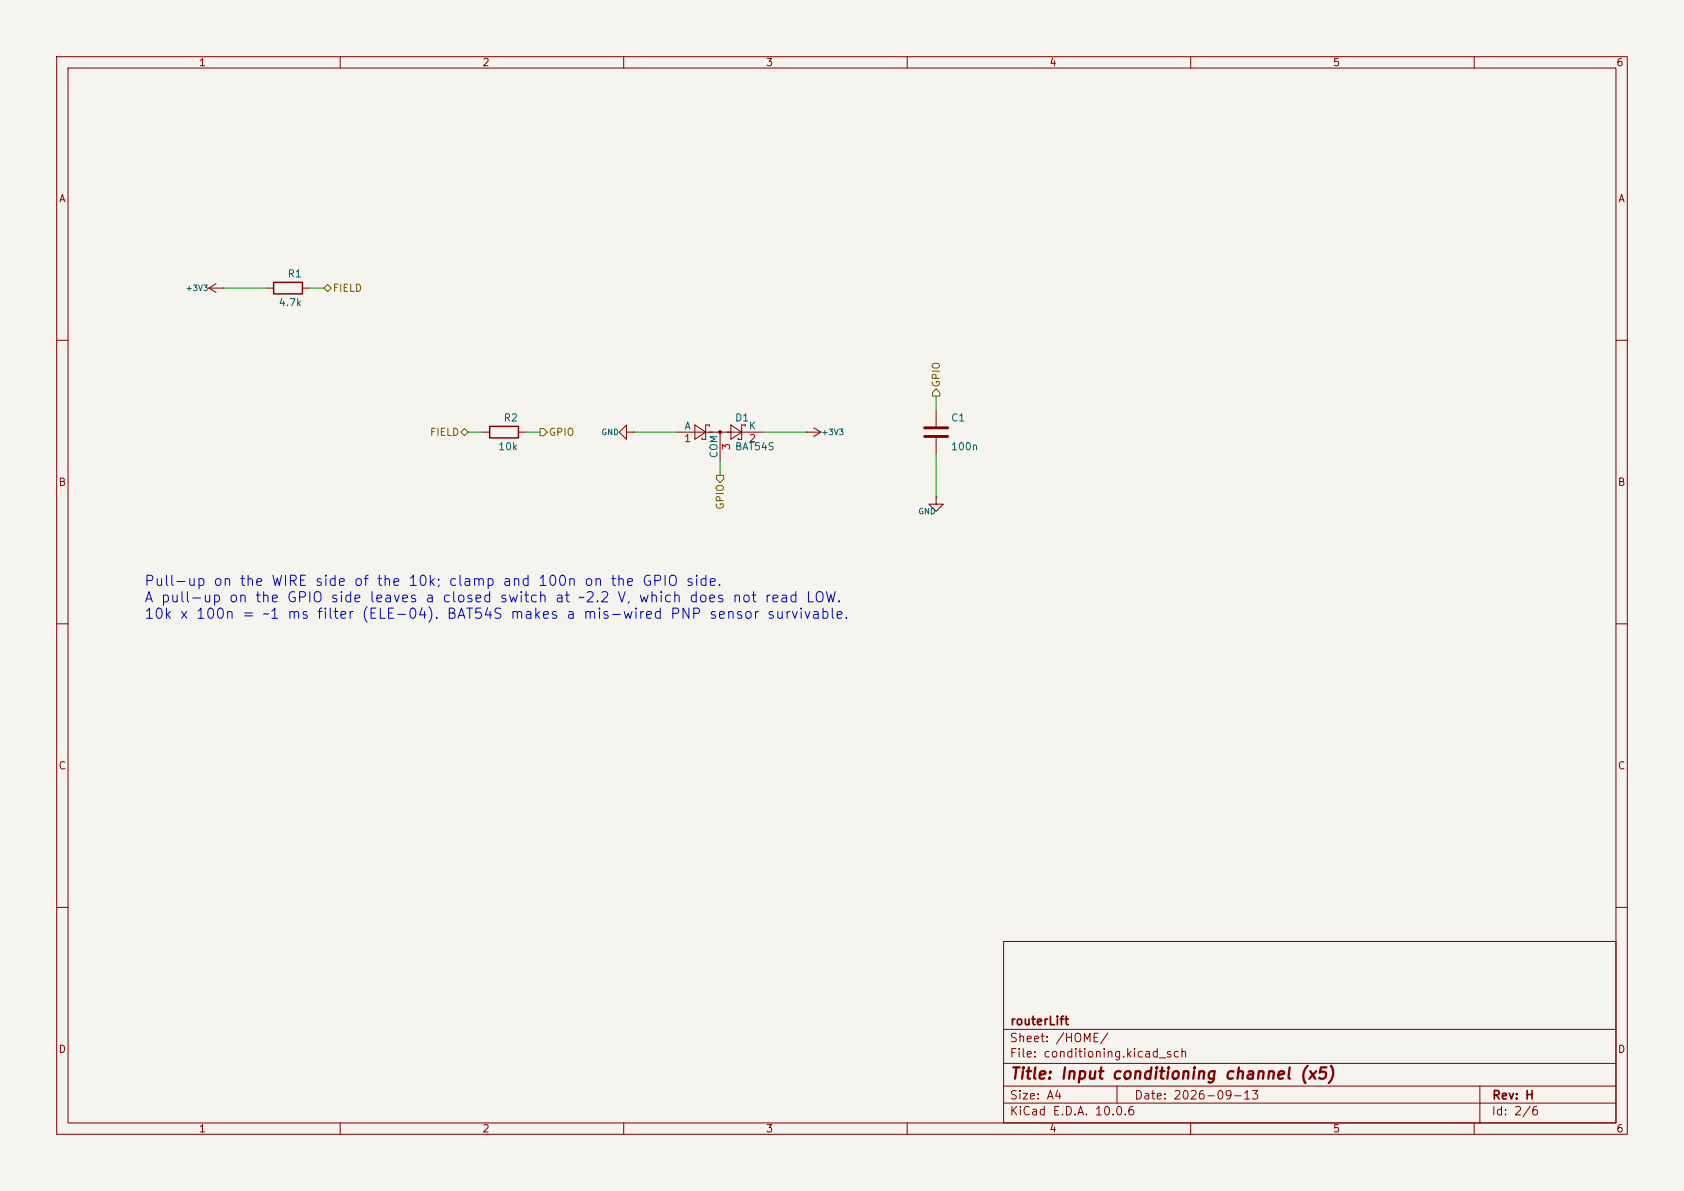
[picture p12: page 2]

GPIO Pull-up on the WIRE side of the 10k; clamp and 100n on the GPIO side.

A pull-up on the GPIO side leaves a closed switch at ~2.2 V, which does not read LOW.
10k x 100n = ~1 ms filter (ELE-04). BAT54S makes a mis-wired PNP sensor survivable.

routerLift
Sheet: /HOME/
File: conditioning.kicad_sch
Title: Input conditioning channel (x5)

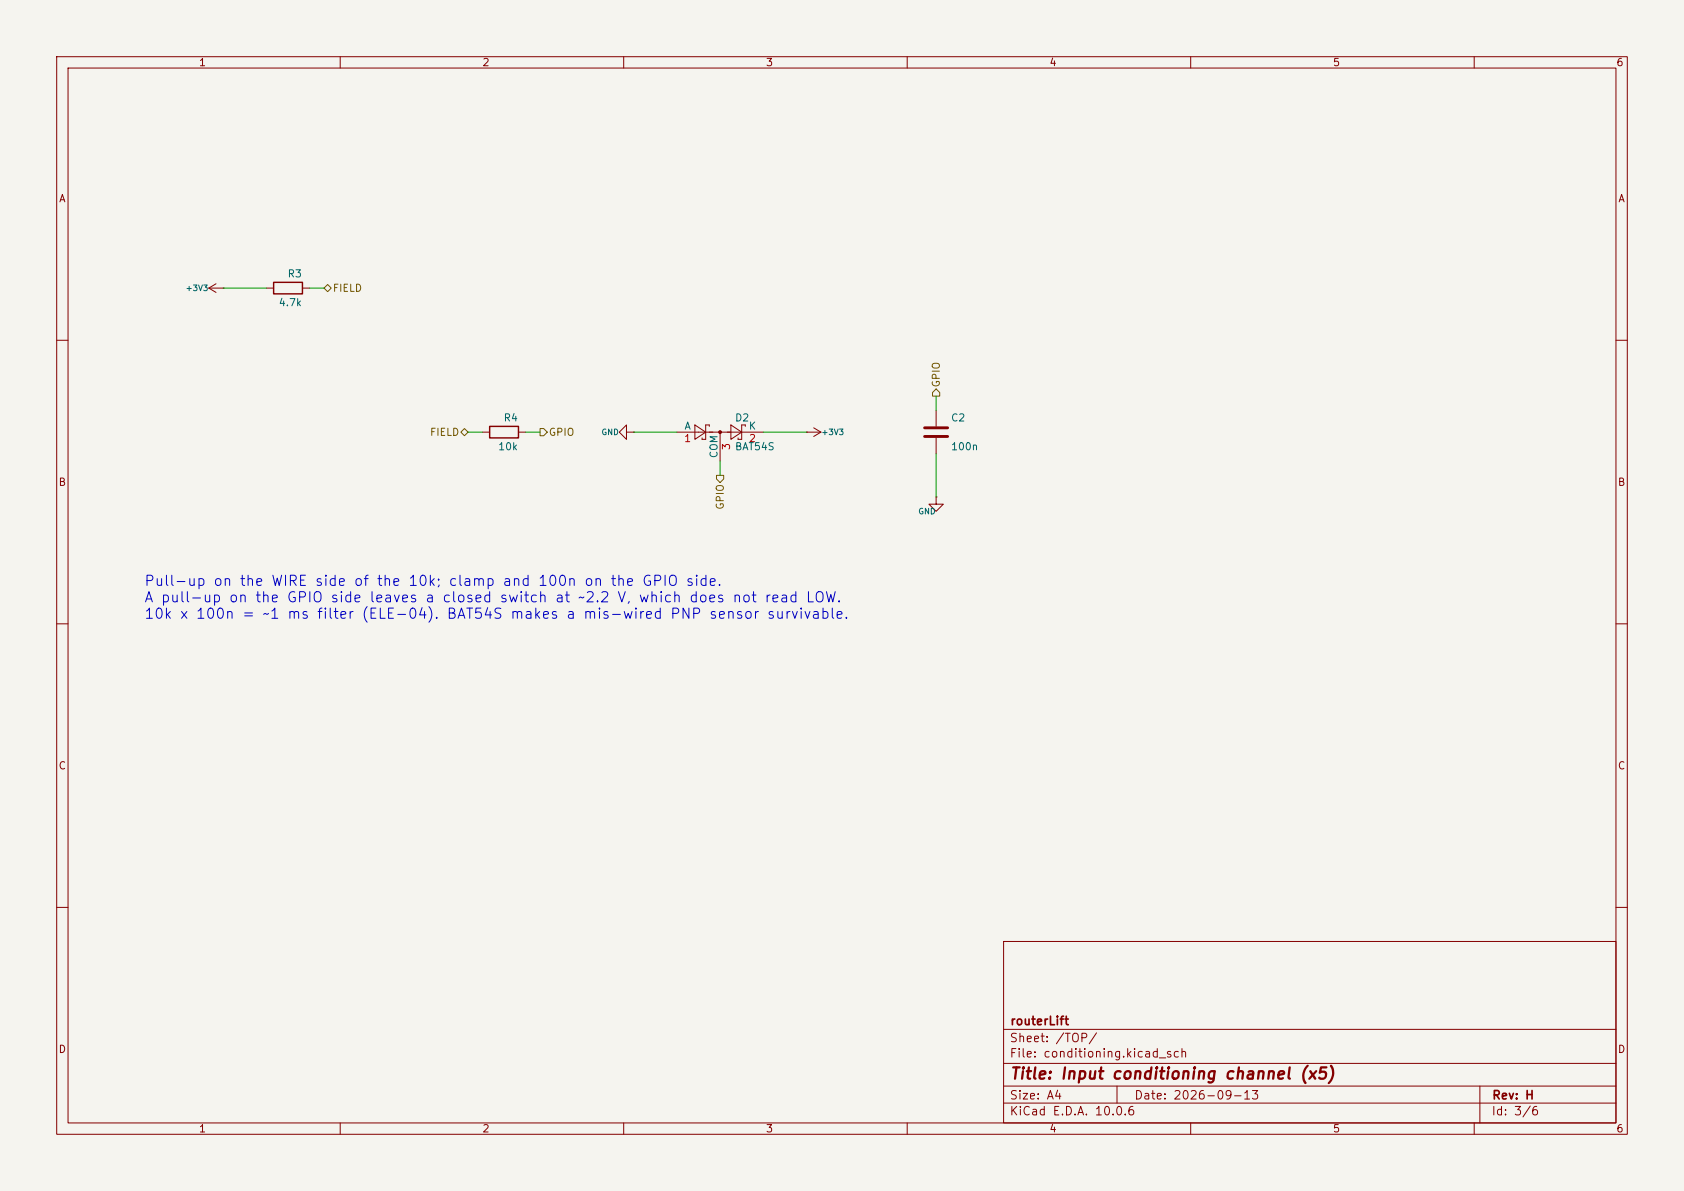
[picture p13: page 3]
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

routerLift
Sheet: /TOP/
File: conditioning.kicad_sch
Title: Input conditioning channel (x5)

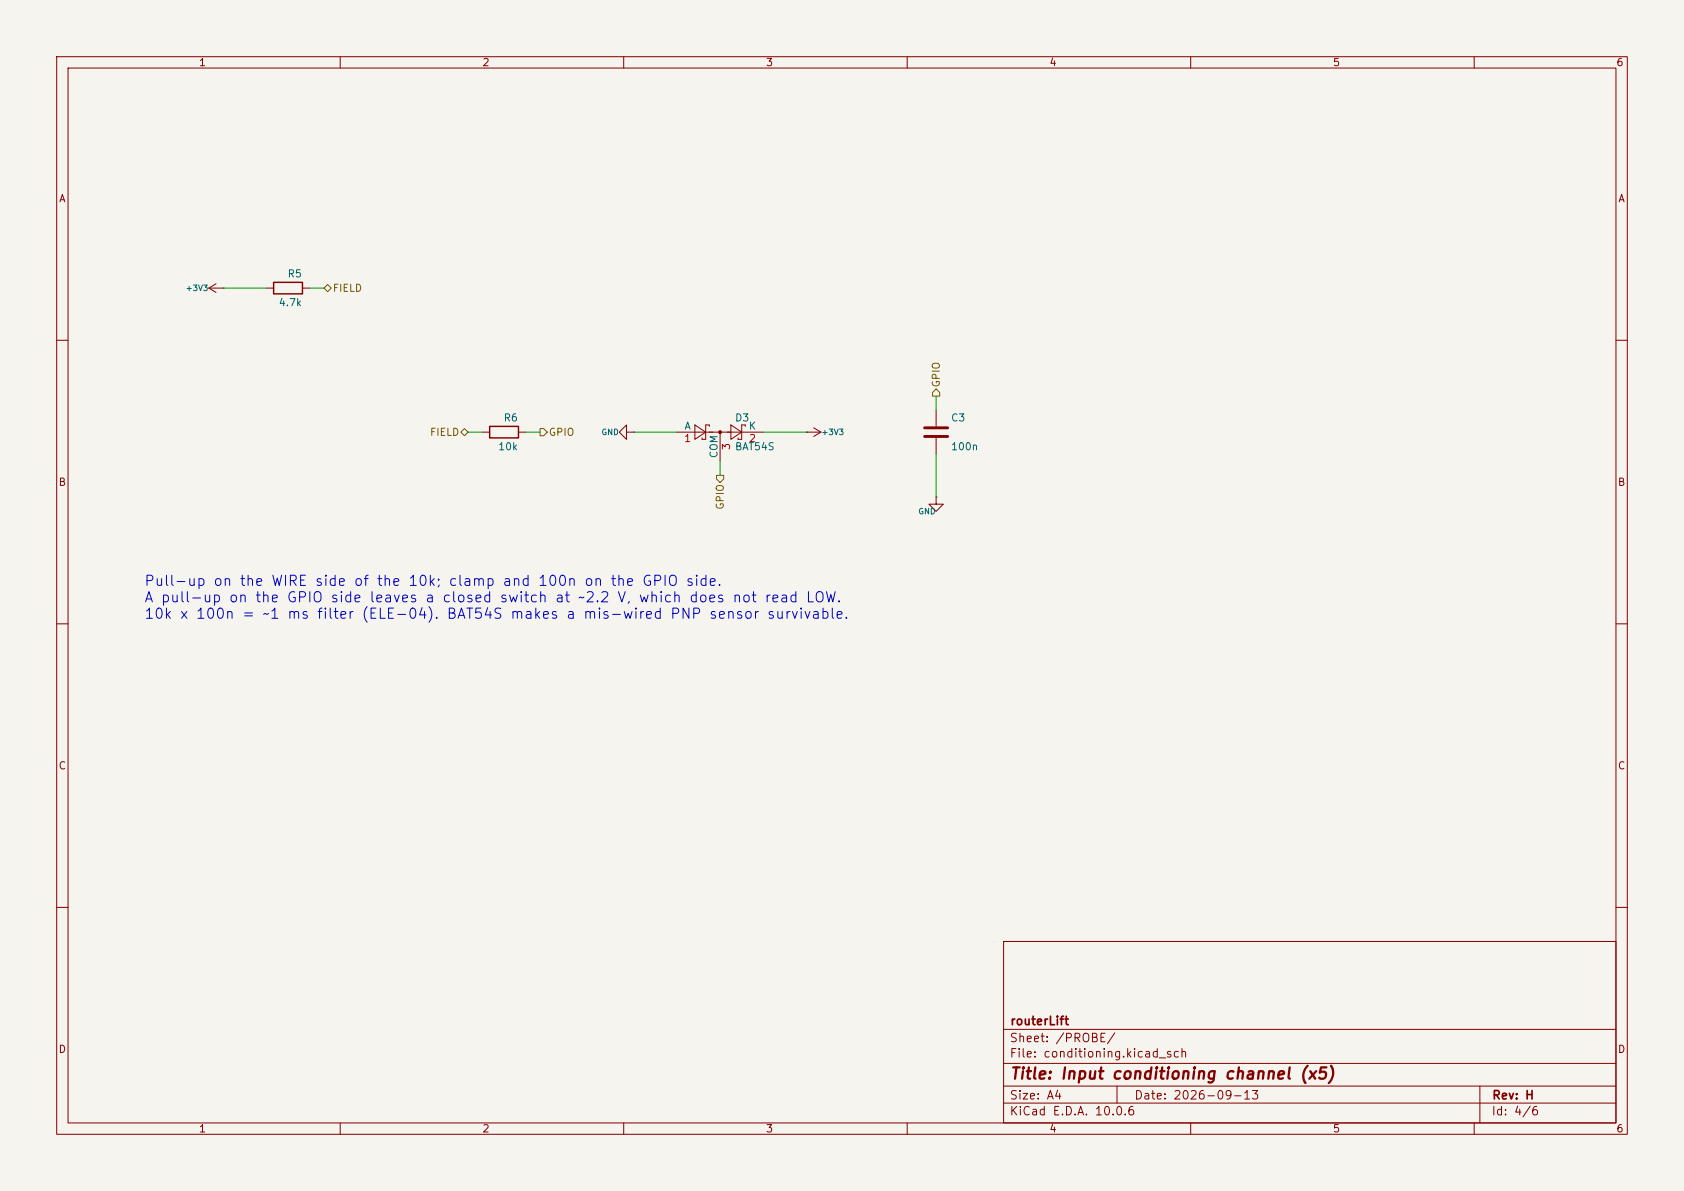
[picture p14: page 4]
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

routerLift
Sheet: /PROBE/
File: conditioning.kicad_sch
Title: Input conditioning channel (x5)

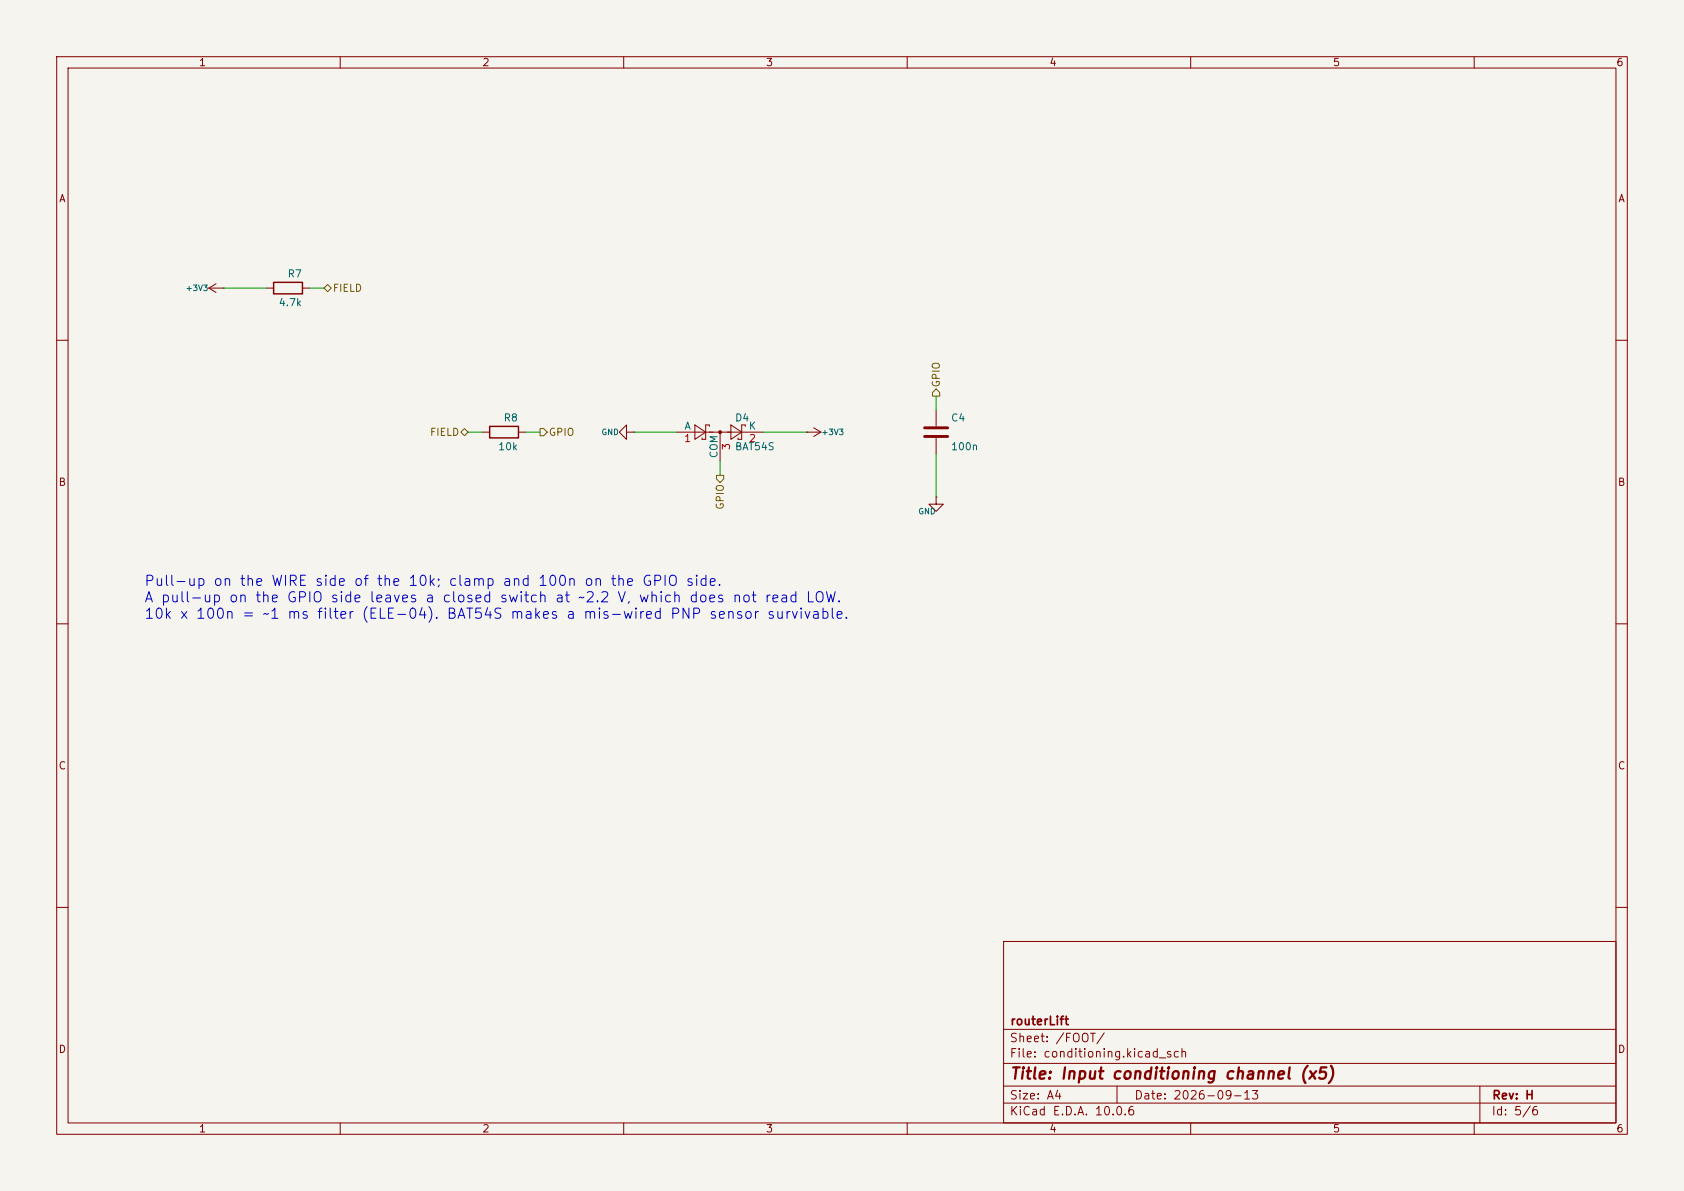
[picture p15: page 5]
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

routerLift
Sheet: /FOOT/
File: conditioning.kicad_sch
Title: Input conditioning channel (x5)

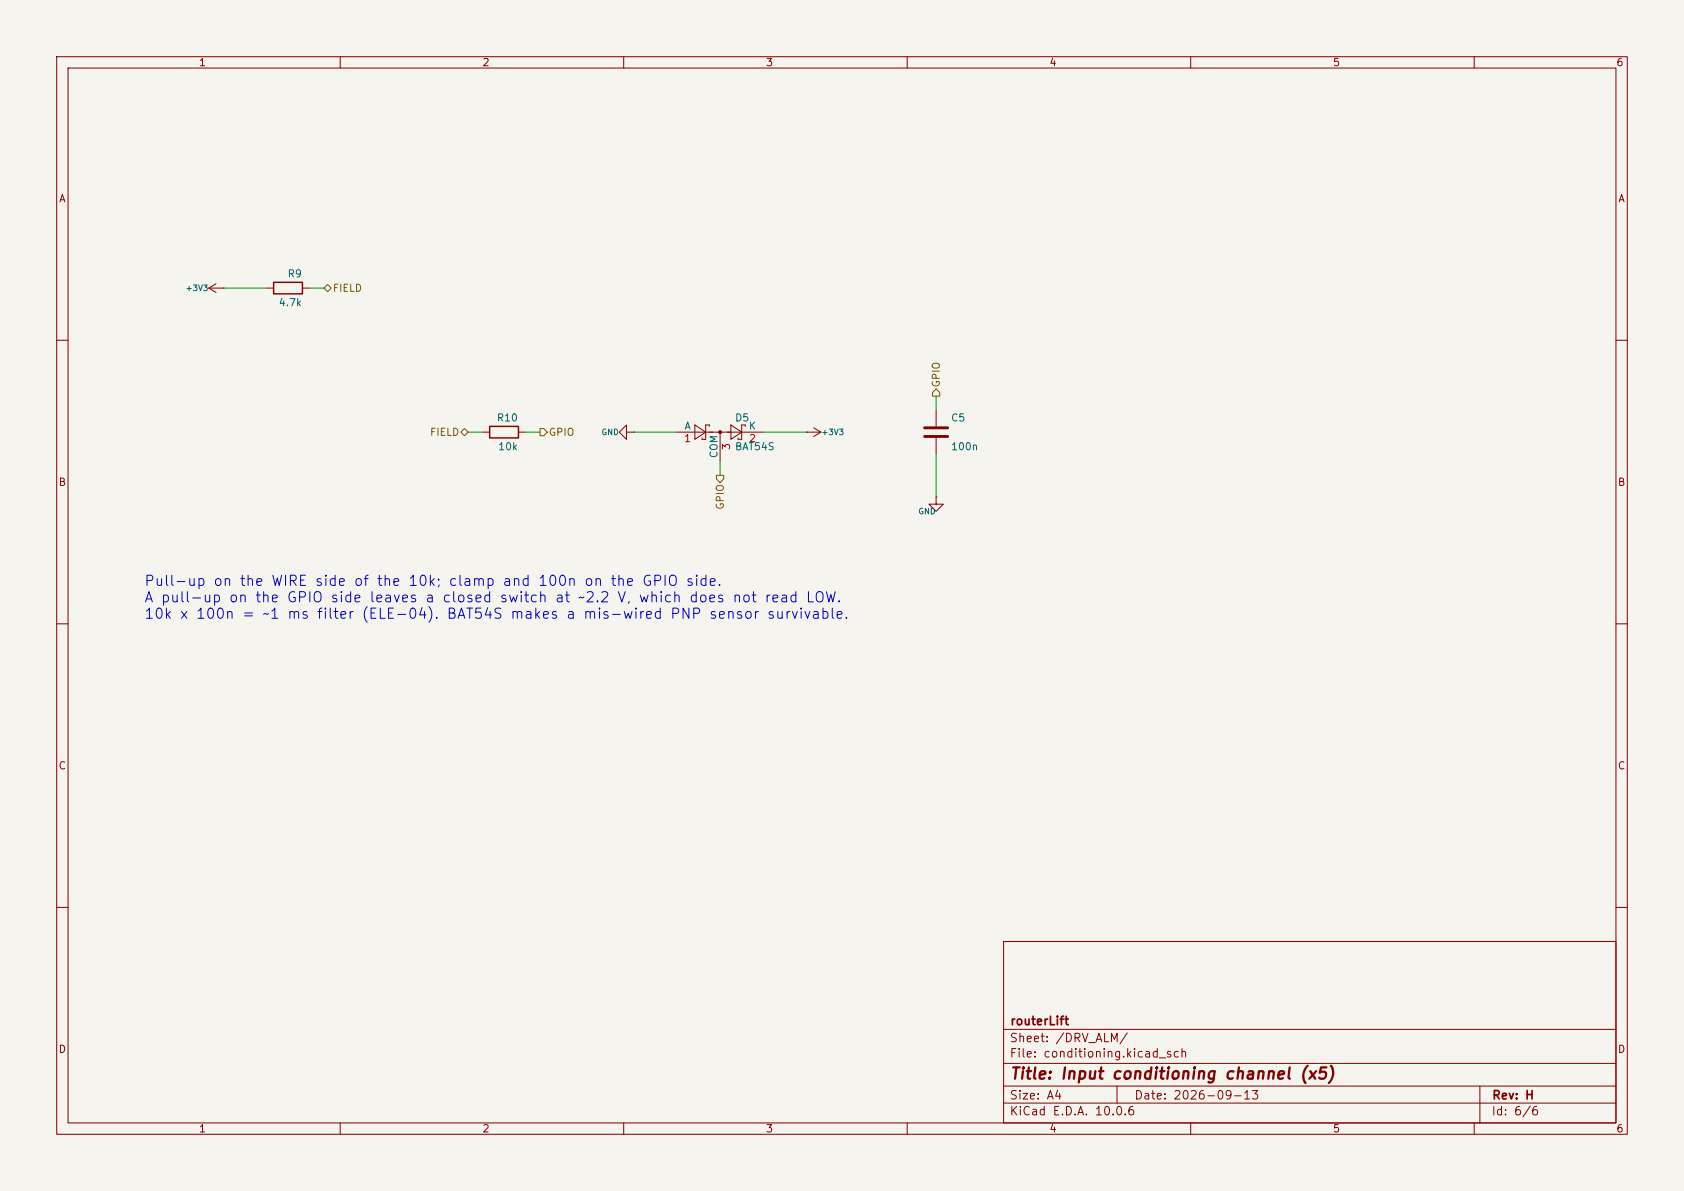
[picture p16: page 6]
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

routerLift
Sheet: /DRV_ALM/
File: conditioning.kicad_sch
Title: Input conditioning channel (x5)

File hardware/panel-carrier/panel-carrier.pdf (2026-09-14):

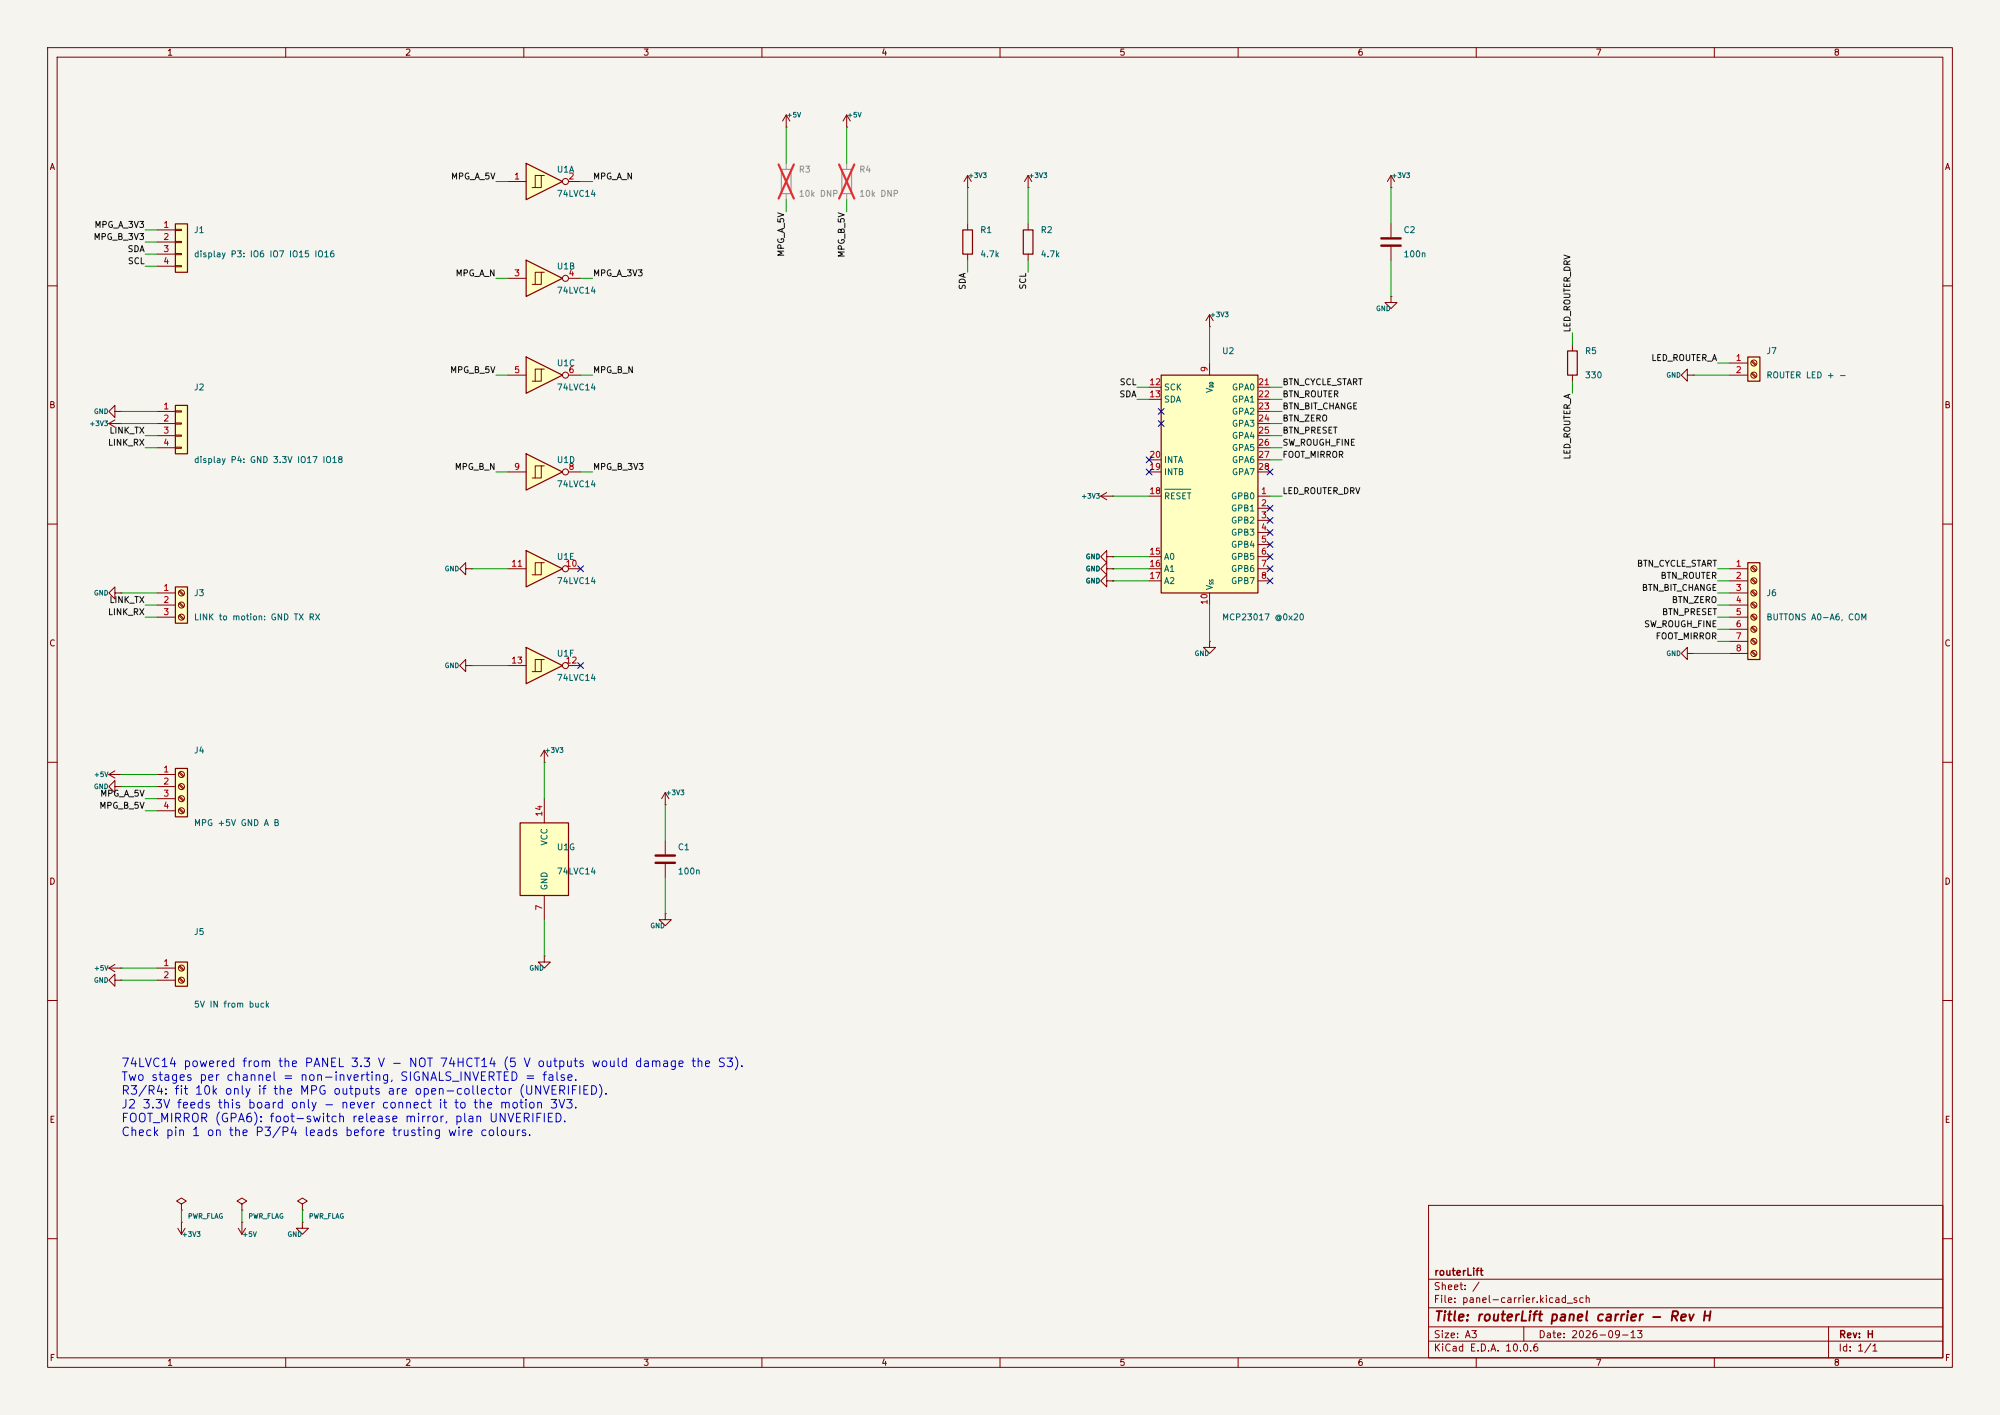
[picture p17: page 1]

Two stages per channel = non-inverting, SIGNALS_INVERTED = false.
R3/R4: fit 10k only if the MPG outputs are open-collector (UNVERIFIED).
J2 3.3V feeds this board only - never connect it to the motion 3V3.
FOOT_MIRROR (GPA6): foot-switch release mirror, plan UNVERIFIED.
Check pin 1 on the P3/P4 leads before trusting wire colours.

routerLift
Sheet: /
File: panel-carrier.kicad_sch
Title: routerLift panel carrier - Rev H

Size: A3 | Rev: H | F Date: 2026-09-13
KiCad E.D.A. 10.0.6 | Id: 1/1

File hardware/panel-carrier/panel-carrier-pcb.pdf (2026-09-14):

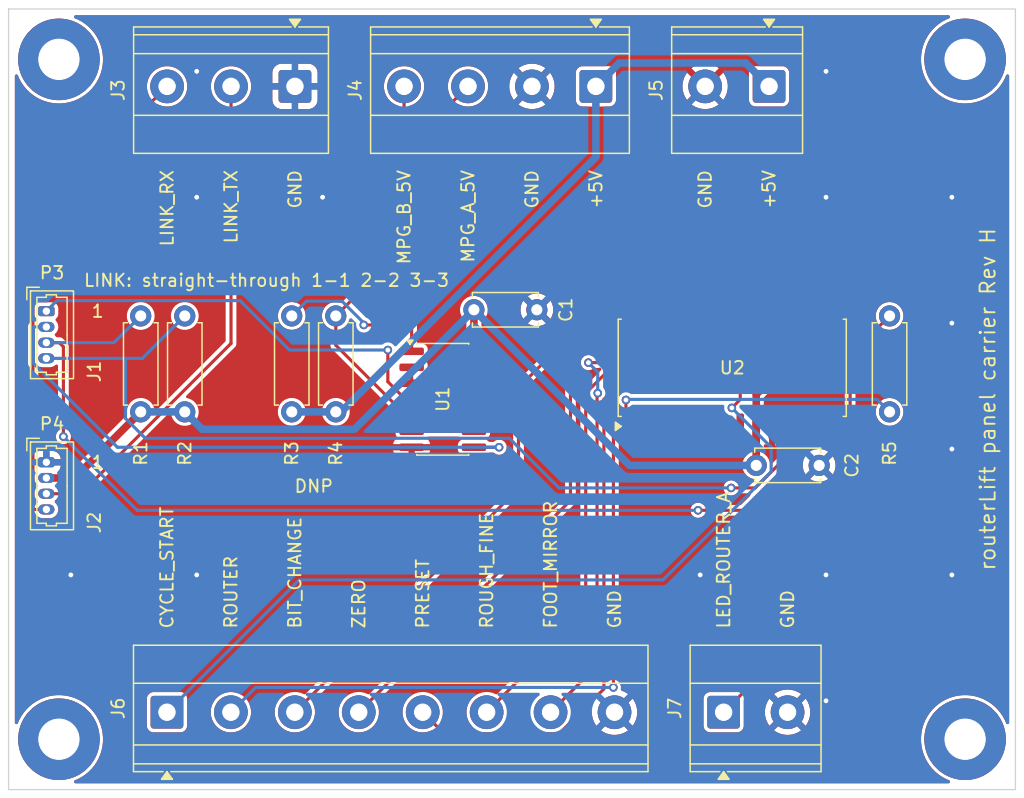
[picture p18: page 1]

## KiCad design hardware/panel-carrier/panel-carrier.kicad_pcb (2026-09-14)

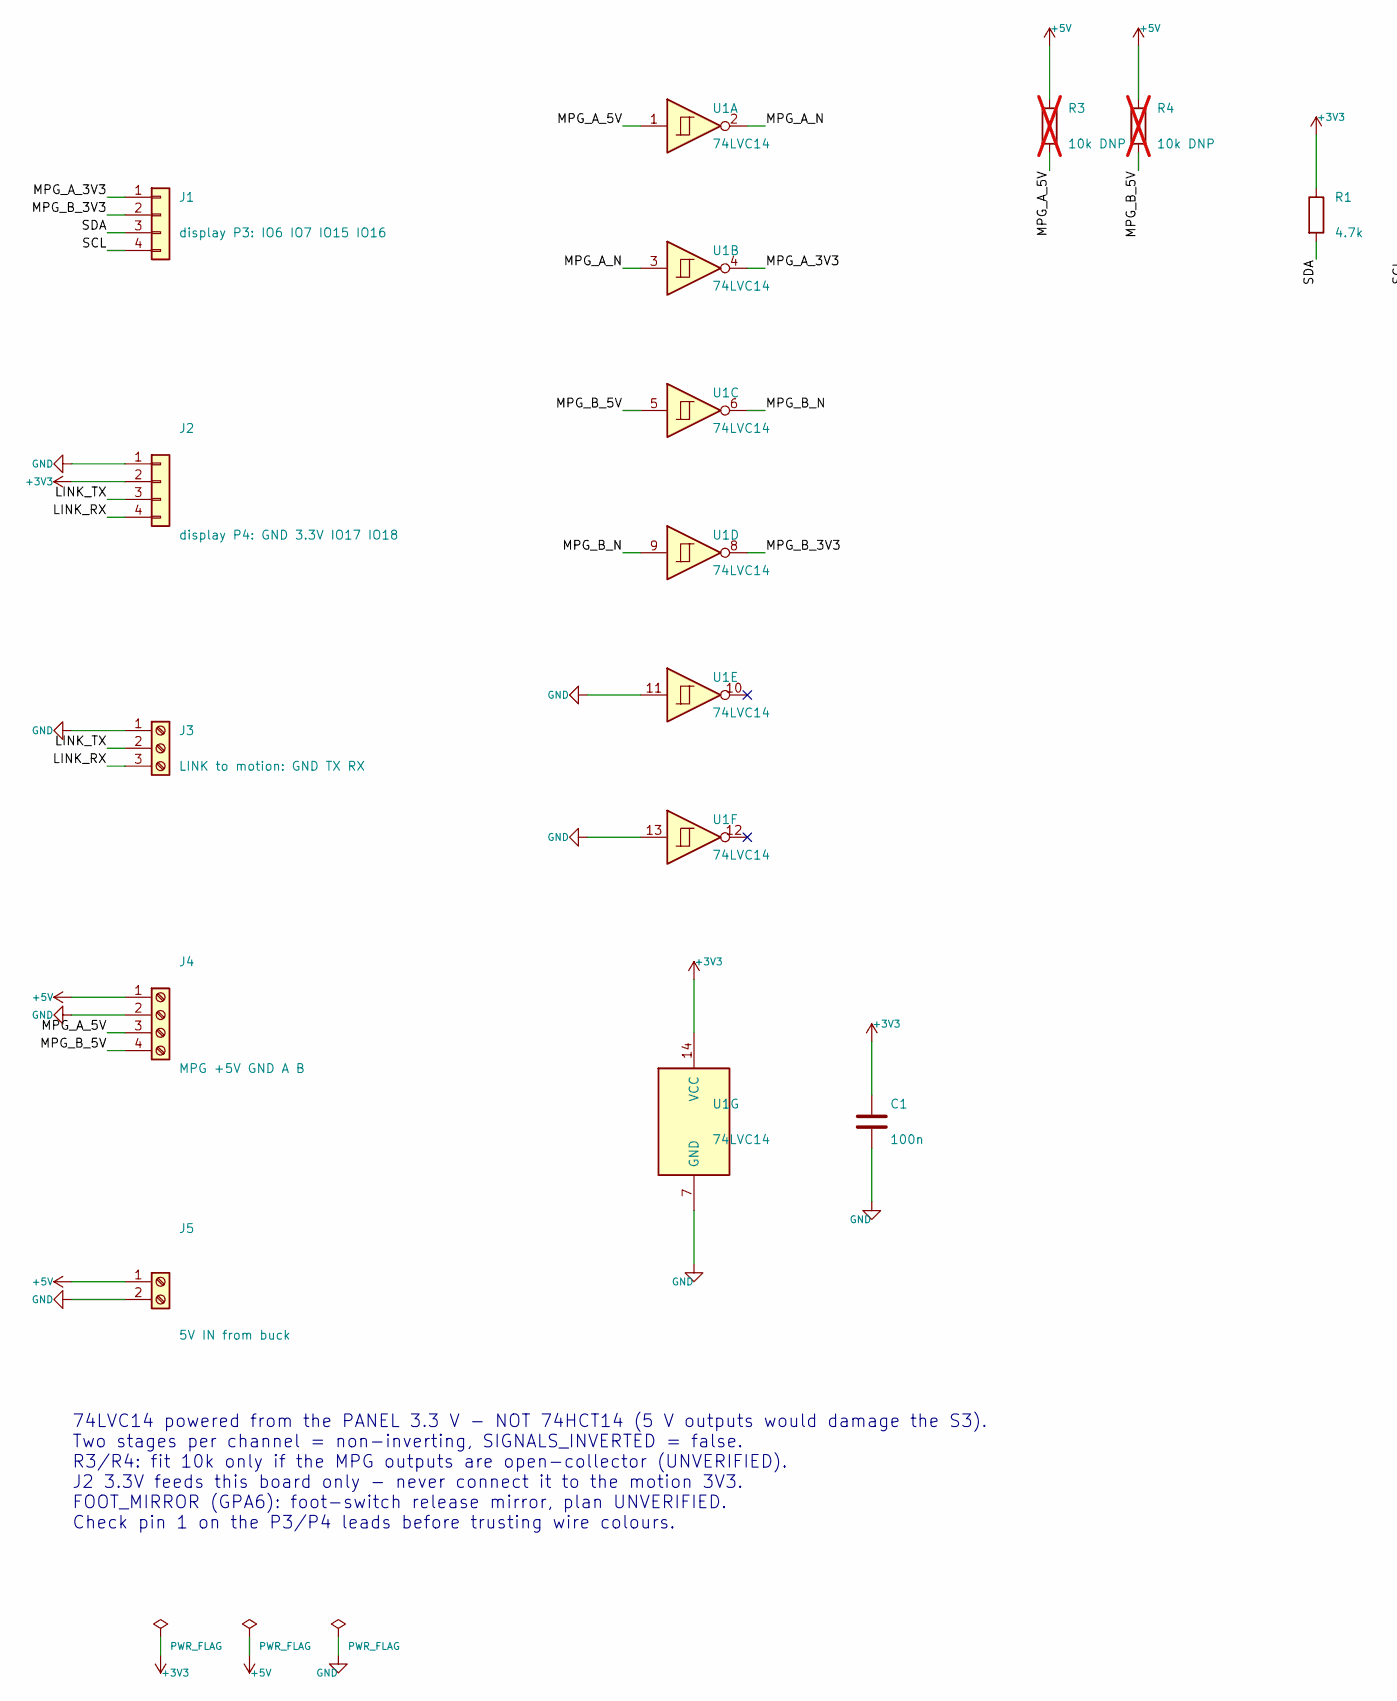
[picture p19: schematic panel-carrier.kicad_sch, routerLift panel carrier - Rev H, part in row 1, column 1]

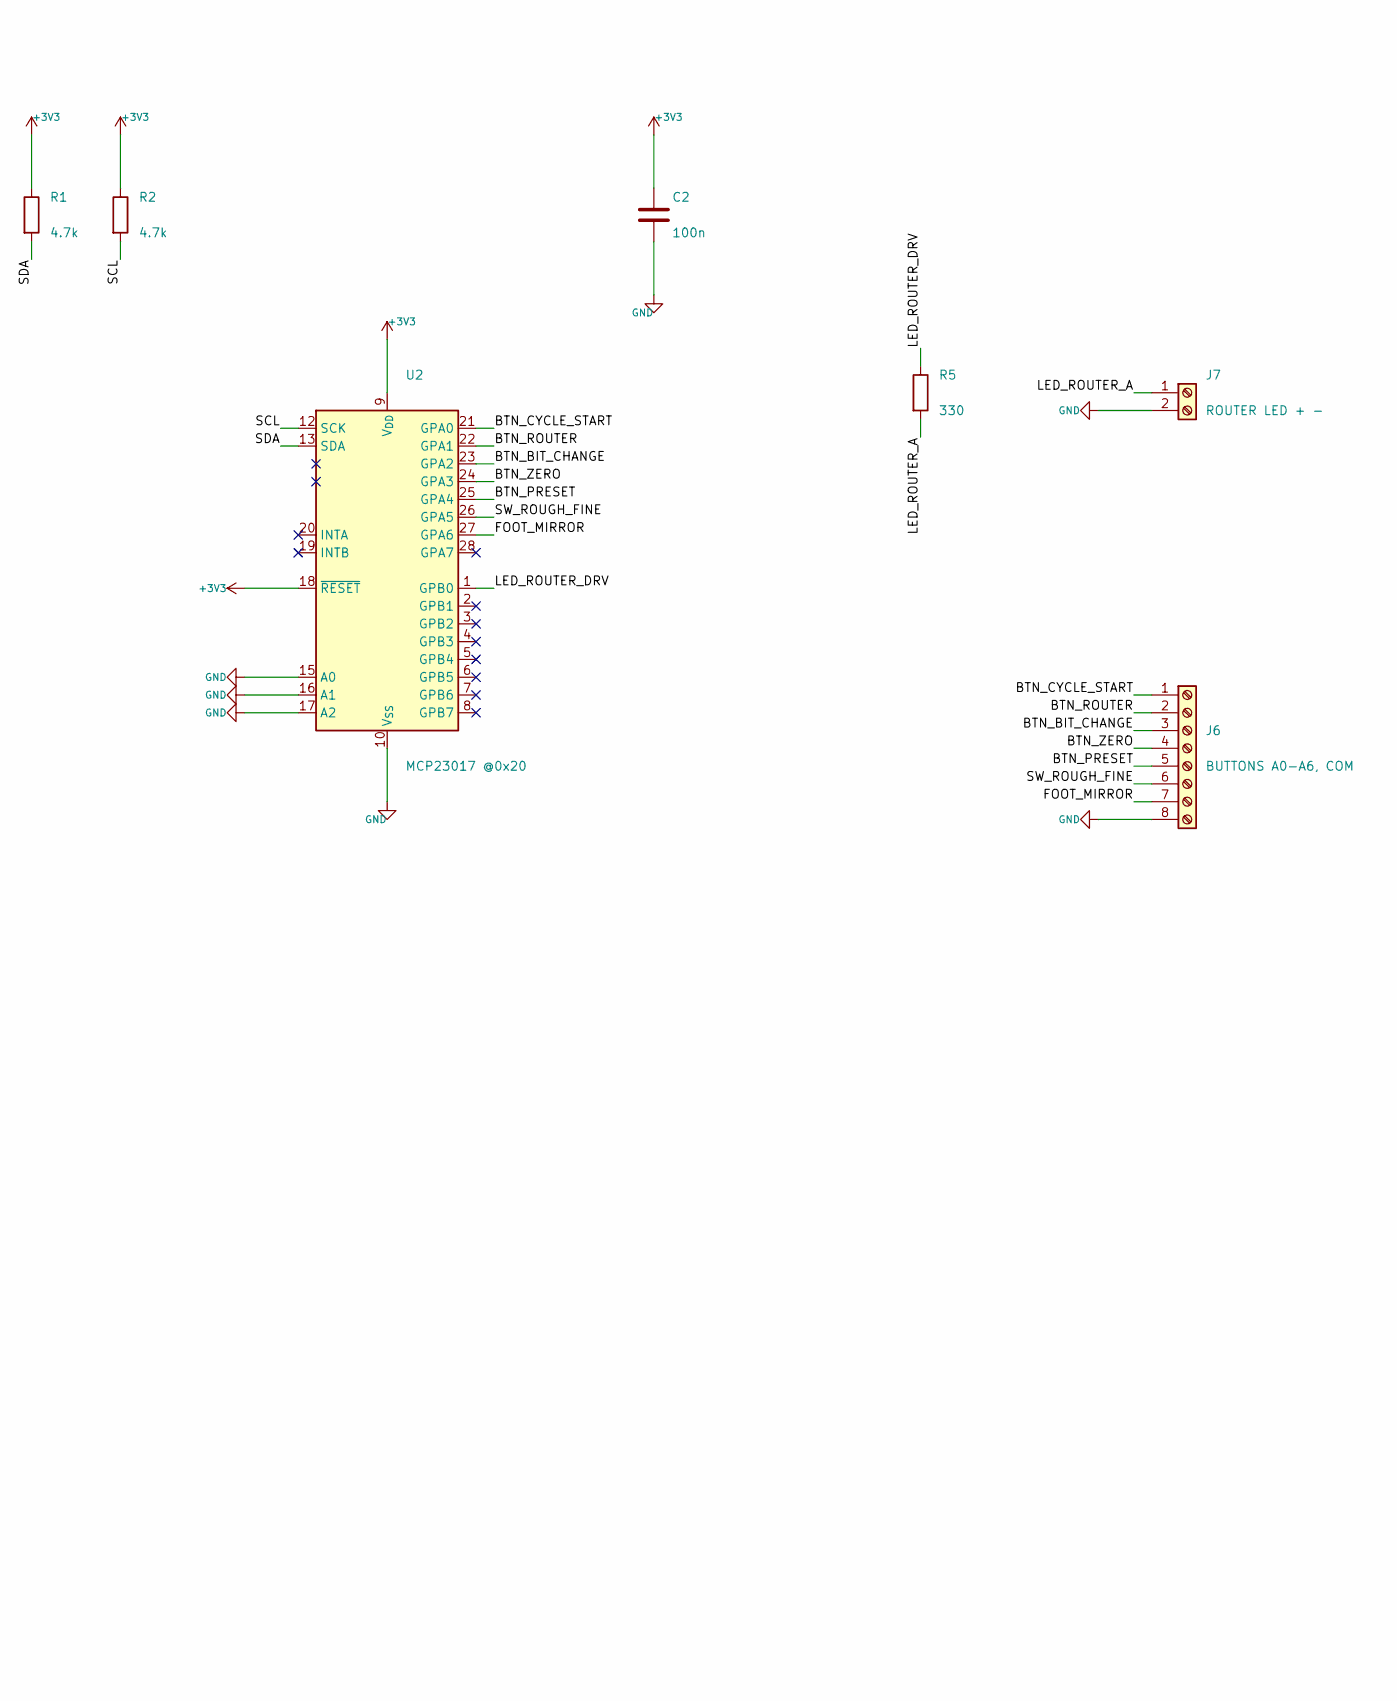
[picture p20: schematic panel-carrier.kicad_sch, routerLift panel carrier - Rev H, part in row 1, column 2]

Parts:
C1, C2: 100n; C_Disc_D5.0mm_W2.5mm_P5.00mm
J1: display P3: IO6 IO7 IO15 IO16; Molex_PicoBlade_53047-0410_1x04_P1.25mm_Vertical
J2: display P4: GND 3.3V IO17 IO18; Molex_PicoBlade_53047-0410_1x04_P1.25mm_Vertical
J3: LINK to motion: GND TX RX; TerminalBlock_Phoenix_MKDS-1,5-3-5.08_1x03_P5.08mm_Horizont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
J4: MPG +5V GND A B; TerminalBlock_Phoenix_MKDS-1,5-4-5.08_1x04_P5.08mm_Horizont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
J5: 5V IN from buck; TerminalBlock_Phoenix_MKDS-1,5-2-5.08_1x02_P5.08mm_Horizont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
J6: BUTTONS A0-A6, COM; TerminalBlock_Phoenix_MKDS-1,5-8-5.08_1x08_P5.08mm_Horizont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
J7: ROUTER LED + -; TerminalBlock_Phoenix_MKDS-1,5-2-5.08_1x02_P5.08mm_Horizont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
R1, R2: 4.7k; R_Axial_DIN0207_L6.3mm_D2.5mm_P7.62mm_Horizontal
R3, R4: 10k DNP; R_Axial_DIN0207_L6.3mm_D2.5mm_P7.62mm_Horizontal; not fitted
R5: 330; R_Axial_DIN0207_L6.3mm_D2.5mm_P7.62mm_Horizontal
U1: 74LVC14; SOIC-14_3.9x8.7mm_P1.27mm
U2: MCP23017 @0x20; SOIC-28W_7.5x17.9mm_P1.27mm

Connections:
+3V3: C1.1, C2.1, J2.2, R1.1, R2.1, U1.14 (VCC), U2.9 (V_{DD}), U2.18 (~RESET)
+5V: J4.1, J5.1, R3.1, R4.1
/BTN_BIT_CHANGE: J6.3, U2.23 (GPA2)
/BTN_CYCLE_START: J6.1, U2.21 (GPA0)
/BTN_PRESET: J6.5, U2.25 (GPA4)
/BTN_ROUTER: J6.2, U2.22 (GPA1)
/BTN_ZERO: J6.4, U2.24 (GPA3)
/FOOT_MIRROR: J6.7, U2.27 (GPA6)
/LED_ROUTER_A: J7.1, R5.2
/LED_ROUTER_DRV: R5.1, U2.1 (GPB0)
/LINK_RX: J2.4, J3.3
/LINK_TX: J2.3, J3.2
/MPG_A_3V3: J1.1, U1.4
/MPG_A_5V: J4.3, R3.2, U1.1
/MPG_A_N: U1.2, U1.3
/MPG_B_3V3: J1.2, U1.8
/MPG_B_5V: J4.4, R4.2, U1.5
/MPG_B_N: U1.6, U1.9
/SCL: J1.4, R2.2, U2.12 (SCK)
/SDA: J1.3, R1.2, U2.13 (SDA)
/SW_ROUGH_FINE: J6.6, U2.26 (GPA5)
GND: C1.2, C2.2, J2.1, J3.1, J4.2, J5.2, J6.8, J7.2, U1.7 (GND), U1.11, U1.13, U2.10 (V_{SS}), U2.15 (A0), U2.16 (A1), U2.17 (A2)

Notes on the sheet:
74LVC14 powered from the PANEL 3.3 V - NOT 74HCT14 (5 V outputs would damage the S3). Two stages per channel = non-inverting, SIGNALS_INVERTED = false. R3/R4: fit 10k only if the MPG outputs are open-collector (UNVERIFIED). J2 3.3V feeds this board only - never connect it to the motion 3V3. FOOT_MI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

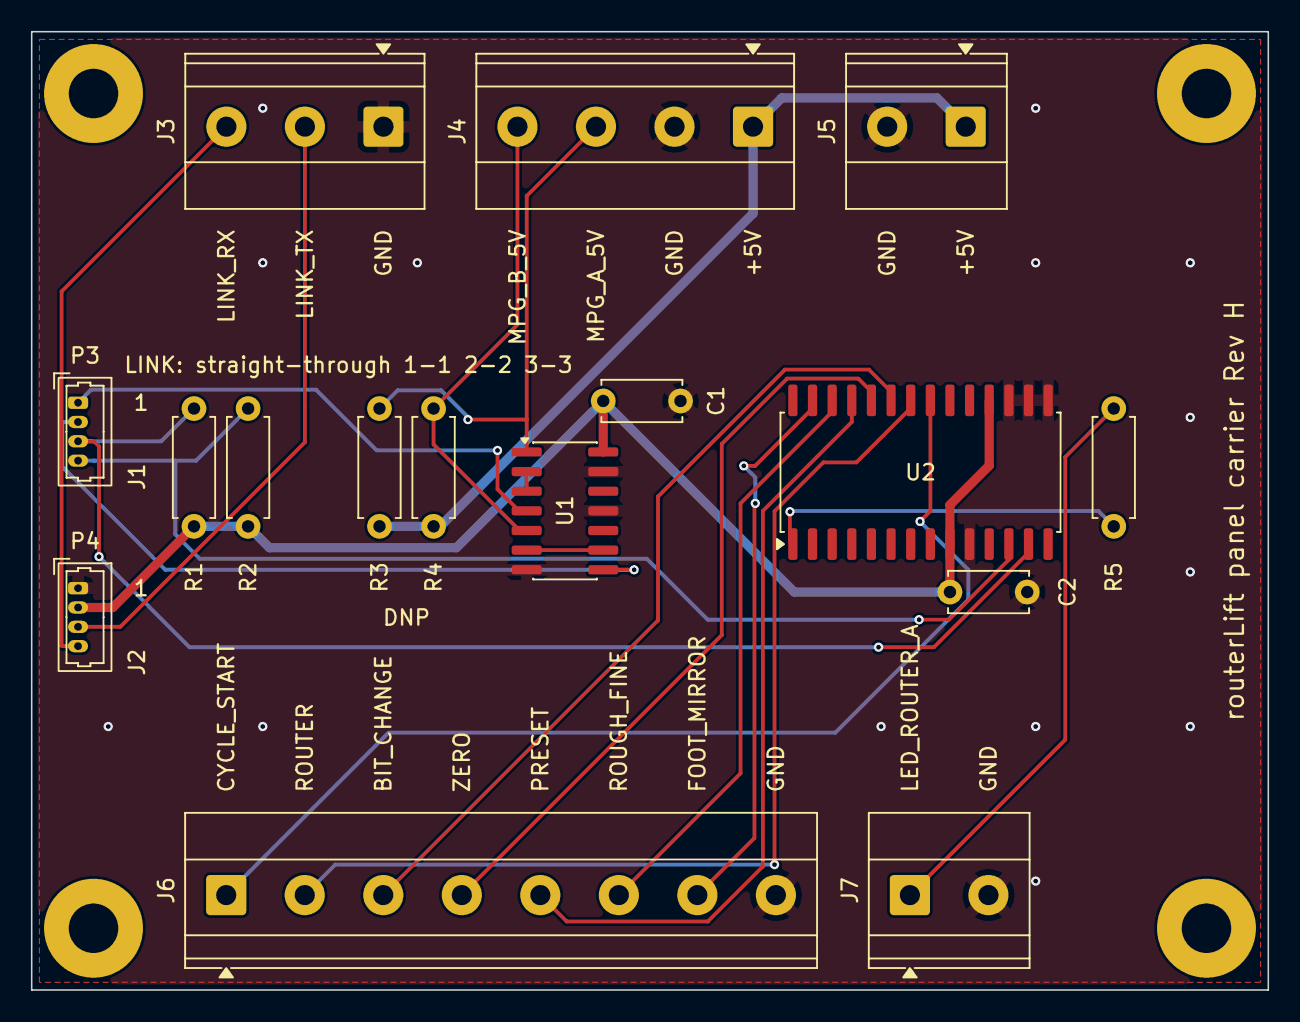
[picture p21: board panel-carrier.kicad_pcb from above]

Board: 2 copper layers, 80.0 x 62.0 mm, 20 parts (0 on the bottom side), 22 nets.

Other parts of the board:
H1, H2, H3, H4: M3; MountingHole_3.2mm_M3_Pad

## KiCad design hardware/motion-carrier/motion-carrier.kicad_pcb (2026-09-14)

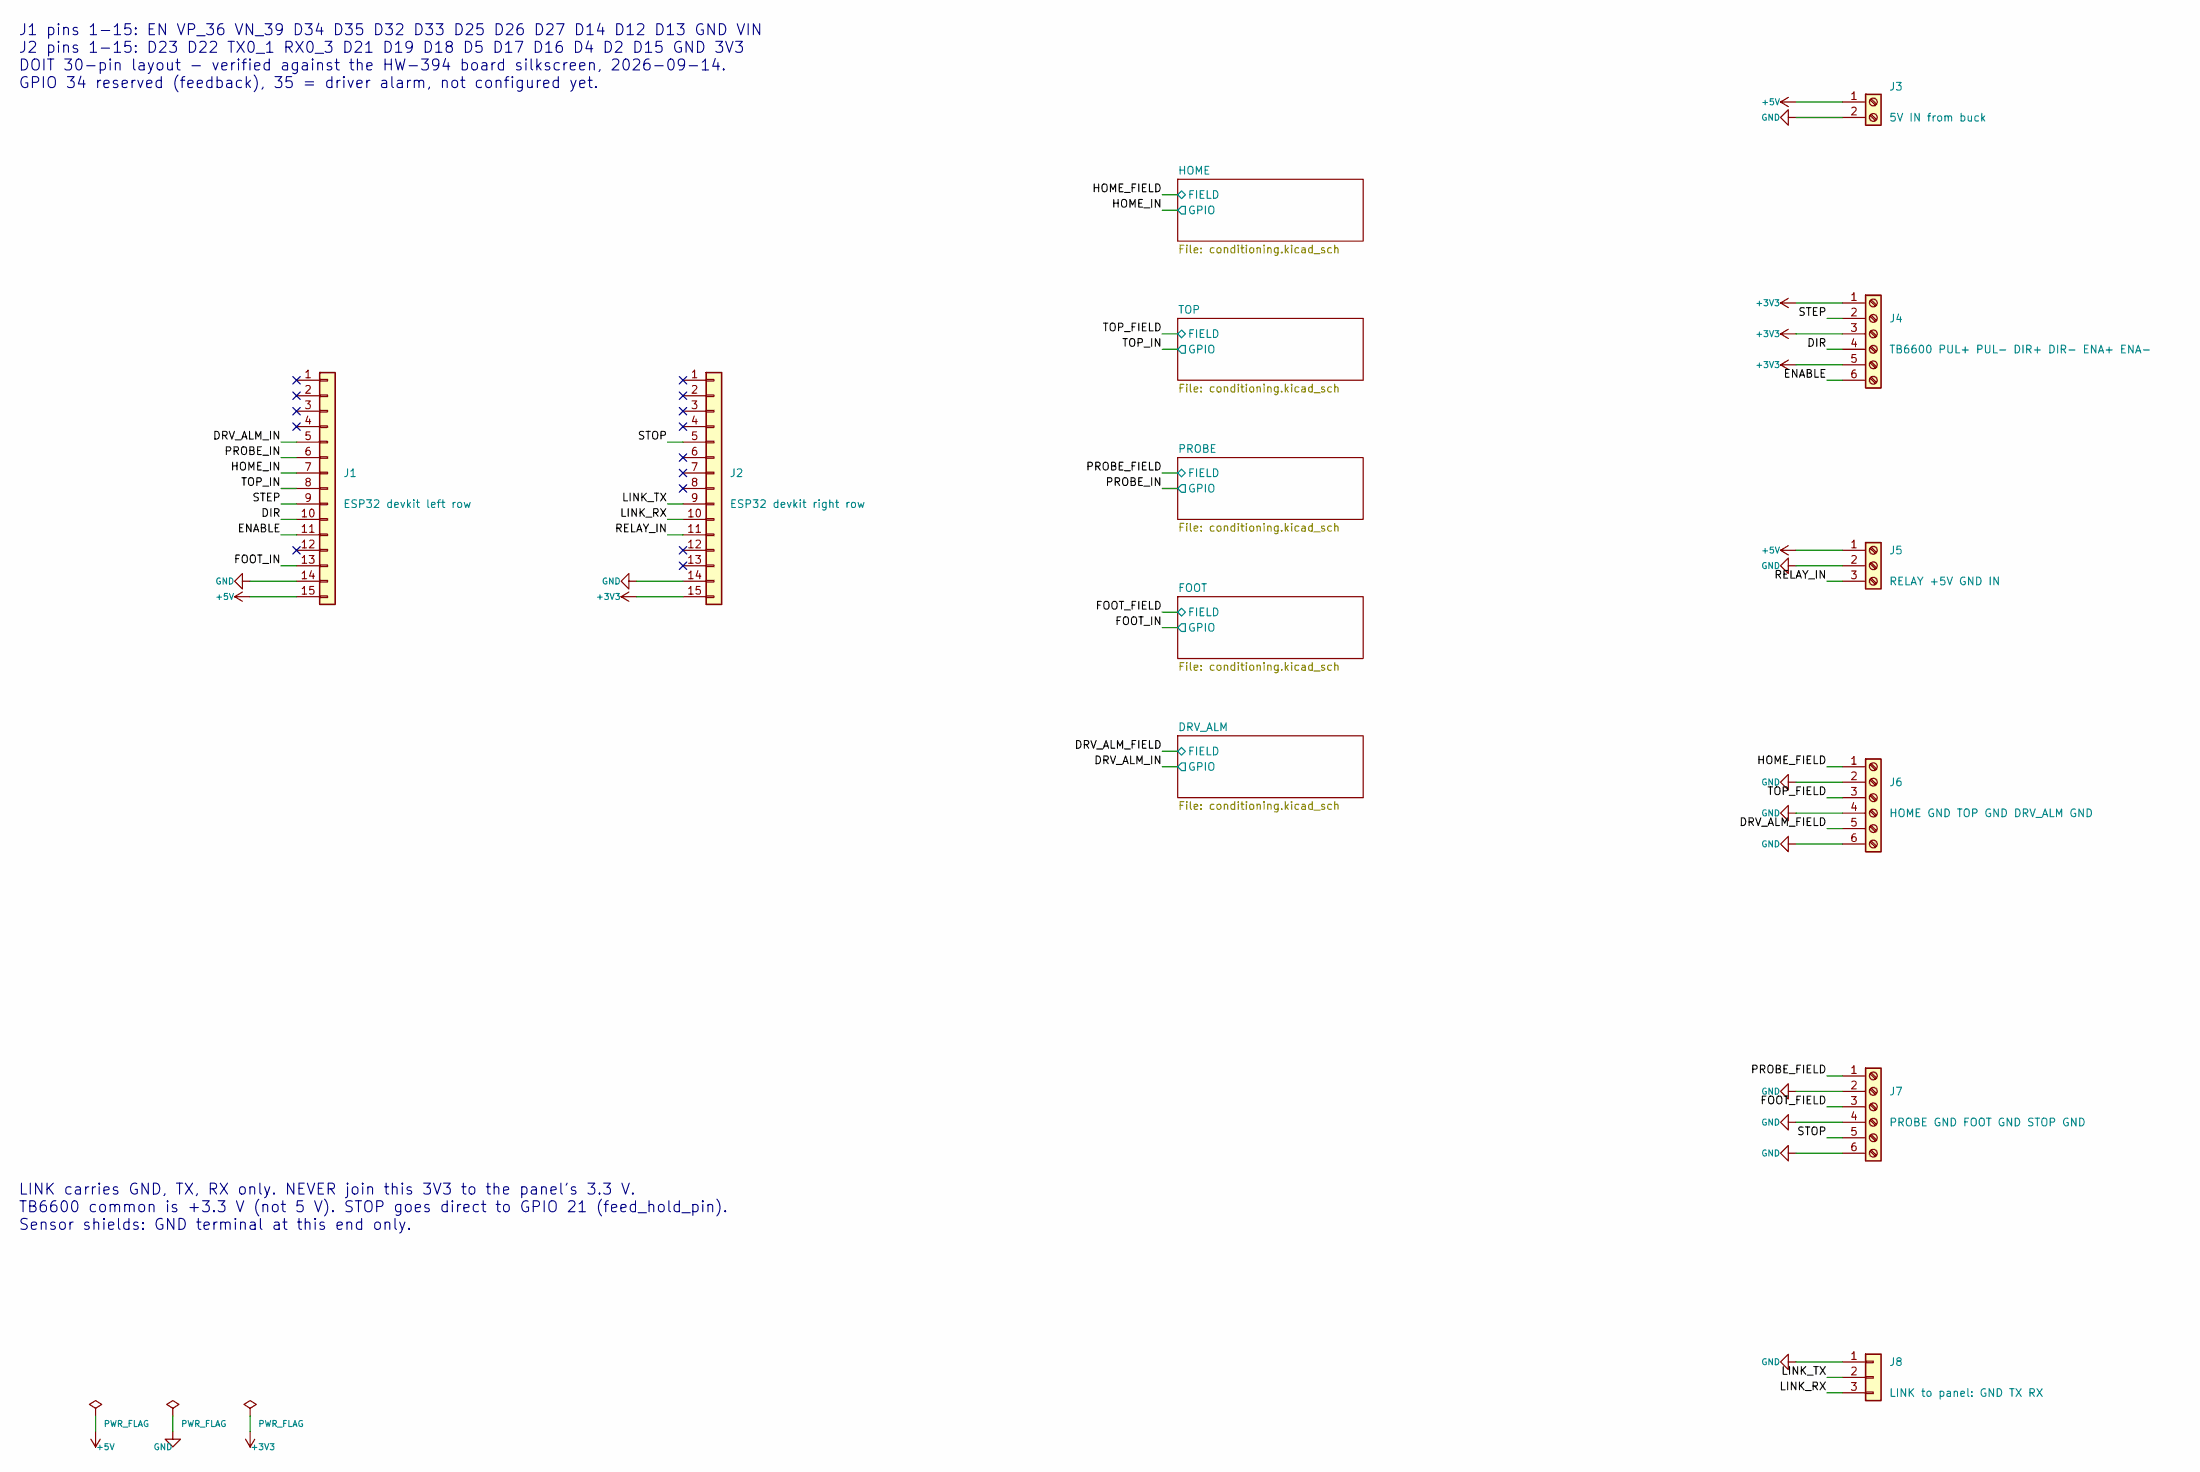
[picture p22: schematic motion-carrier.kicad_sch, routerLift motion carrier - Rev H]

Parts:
J1: ESP32 devkit left row; PinSocket_1x15_P2.54mm_Vertical
J2: ESP32 devkit right row; PinSocket_1x15_P2.54mm_Vertical
J3: 5V IN from buck; TerminalBlock_Phoenix_MKDS-1,5-2-5.08_1x02_P5.08mm_Horizont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
J4: TB6600 PUL+ PUL- DIR+ DIR- ENA+ ENA-; TerminalBlock_Phoenix_MKDS-1,5-6-5.08_1x06_P5.08mm_Horizont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
J5: RELAY +5V GND IN; TerminalBlock_Phoenix_MKDS-1,5-3-5.08_1x03_P5.08mm_Horizont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
J6: HOME GND TOP GND DRV_ALM GND; TerminalBlock_Phoenix_MKDS-1,5-6-5.08_1x06_P5.08mm_Horizont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
J7: PROBE GND FOOT GND STOP GND; TerminalBlock_Phoenix_MKDS-1,5-6-5.08_1x06_P5.08mm_Horizont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
J8: LINK to panel: GND TX RX; JST_XH_B3B-XH-A_1x03_P2.50mm_Vertical

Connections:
+3V3: J2.15, J4.1, J4.3, J4.5; also elsewhere on the board
+5V: J1.15, J3.1, J5.1
/DIR: J1.10, J4.4
/DRV_ALM_FIELD: J6.5; also elsewhere on the board
/DRV_ALM_IN: J1.5; also elsewhere on the board
/ENABLE: J1.11, J4.6
/FOOT_FIELD: J7.3; also elsewhere on the board
/FOOT_IN: J1.13; also elsewhere on the board
/HOME_FIELD: J6.1; also elsewhere on the board
/HOME_IN: J1.7; also elsewhere on the board
/LINK_RX: J2.10, J8.3
/LINK_TX: J2.9, J8.2
/PROBE_FIELD: J7.1; also elsewhere on the board
/PROBE_IN: J1.6; also elsewhere on the board
/RELAY_IN: J2.11, J5.3
/STEP: J1.9, J4.2
/STOP: J2.5, J7.5
/TOP_FIELD: J6.3; also elsewhere on the board
/TOP_IN: J1.8; also elsewhere on the board
GND: J1.14, J2.14, J3.2, J5.2, J6.2, J6.4, J6.6, J7.2, J7.4, J7.6, J8.1; also elsewhere on the board

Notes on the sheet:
J1 pins 1-15: EN VP_36 VN_39 D34 D35 D32 D33 D25 D26 D27 D14 D12 D13 GND VIN J2 pins 1-15: D23 D22 TX0_1 RX0_3 D21 D19 D18 D5 D17 D16 D4 D2 D15 GND 3V3 DOIT 30-pin layout - verified against the HW-394 board silkscreen, 2026-09-14. GPIO 34 reserved (feedback), 35 = driver alarm, not configured yet.
LINK carries GND, TX, RX only. NEVER join this 3V3 to the panel's 3.3 V. TB6600 common is +3.3 V (not 5 V). STOP goes direct to GPIO 21 (feed_hold_pin). Sensor shields: GND terminal at this end only.

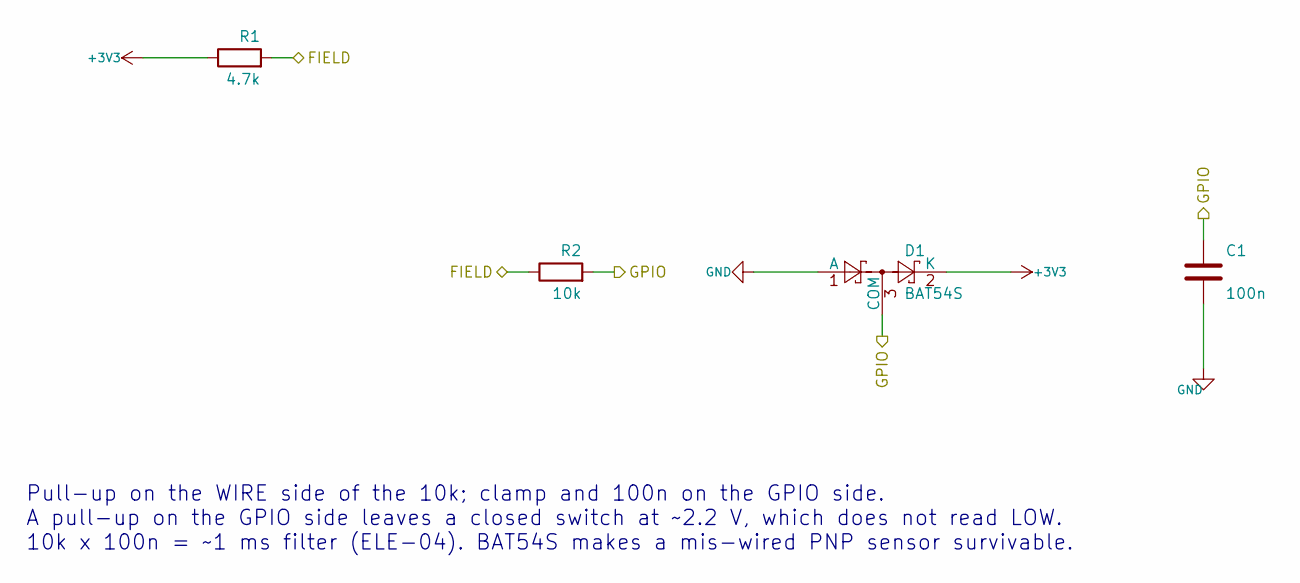
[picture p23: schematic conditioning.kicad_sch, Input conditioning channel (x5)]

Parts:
C1: 100n; C_Disc_D5.0mm_W2.5mm_P5.00mm
D1: BAT54S; SOT-23
R1: 4.7k; R_Axial_DIN0207_L6.3mm_D2.5mm_P7.62mm_Horizontal
R2: 10k; R_Axial_DIN0207_L6.3mm_D2.5mm_P7.62mm_Horizontal

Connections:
+3V3: D1.2 (K), R1.1; also elsewhere on the board
/HOME_FIELD: R1.2, R2.1; also elsewhere on the board
/HOME_IN: C1.1, D1.3 (COM), R2.2; also elsewhere on the board
GND: C1.2, D1.1 (A); also elsewhere on the board

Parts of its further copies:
C2, C3, C4, C5: 100n; C_Disc_D5.0mm_W2.5mm_P5.00mm
D2, D3, D4, D5: BAT54S; SOT-23
R3, R5, R7, R9: 4.7k; R_Axial_DIN0207_L6.3mm_D2.5mm_P7.62mm_Horizontal
R4, R6, R8, R10: 10k; R_Axial_DIN0207_L6.3mm_D2.5mm_P7.62mm_Horizontal

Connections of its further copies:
+3V3: D2.2 (K), D3.2 (K), D4.2 (K), D5.2 (K), R3.1, R5.1, R7.1, R9.1; also elsewhere on the board
/DRV_ALM_FIELD: R9.2, R10.1; also elsewhere on the board
/DRV_ALM_IN: C5.1, D5.3 (COM), R10.2; also elsewhere on the board
/FOOT_FIELD: R7.2, R8.1; also elsewhere on the board
/FOOT_IN: C4.1, D4.3 (COM), R8.2; also elsewhere on the board
/PROBE_FIELD: R5.2, R6.1; also elsewhere on the board
/PROBE_IN: C3.1, D3.3 (COM), R6.2; also elsewhere on the board
/TOP_FIELD: R3.2, R4.1; also elsewhere on the board
/TOP_IN: C2.1, D2.3 (COM), R4.2; also elsewhere on the board
GND: C2.2, C3.2, C4.2, C5.2, D2.1 (A), D3.1 (A), D4.1 (A), D5.1 (A); also elsewhere on the board

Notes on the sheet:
Pull-up on the WIRE side of the 10k; clamp and 100n on the GPIO side. A pull-up on the GPIO side leaves a closed switch at ~2.2 V, which does not read LOW. 10k x 100n = ~1 ms filter (ELE-04). BAT54S makes a mis-wired PNP sensor survivable.

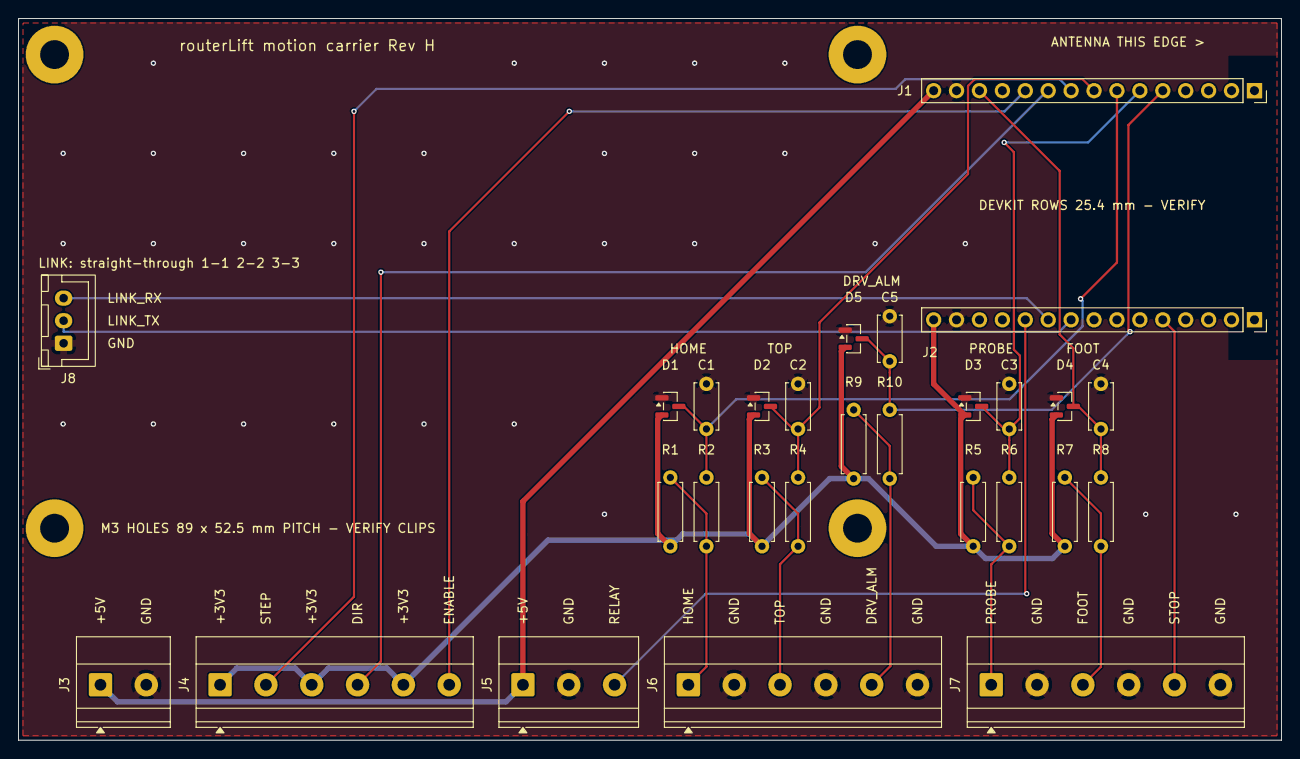
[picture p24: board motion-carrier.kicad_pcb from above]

Board: 2 copper layers, 140.0 x 80.0 mm, 32 parts (0 on the bottom side), 20 nets.

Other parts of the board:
H1, H2, H3, H4: M3; MountingHole_3.2mm_M3_Pad

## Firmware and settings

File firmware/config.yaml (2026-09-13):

# routerLift — FluidNC machine definition
#
# Target: stock FluidNC on a classic ESP32 (NOT ESP32-S3 — FluidNC does not run on it).
# This file is the entire motion-side implementation. No C++ is written for this board.
#
# Companion documents:
#   docs/SCHEMATIC-RevH.svg    terminal-level wiring
#   docs/PINOUT.svg            pin assignment for both controllers
#   docs/UART-PROTOCOL.md      how the HMI talks to this board
#   docs/DESIGN-QA.md          where every value below was decided
#
# ##########################################################################
# #  steps_per_mm AND max_travel_mm COME FROM THE MANUFACTURER SPEC,      #
# #  NOT FROM A MEASUREMENT. Host is a sauter Fraeslift FML-P (not yet    #
# #  bought). Measure on the actual lift before cutting anything.         #
# #  See docs/MECHANICS-RevH.md                                           #
# ##########################################################################

name: routerLift
board: ESP32 devkit v1

# --------------------------------------------------------------------------
# Stepping
# --------------------------------------------------------------------------
stepping:
  engine: RMT
  idle_ms: 255          # 255 = never de-energise (Q17).
                        # NOTE: the FML-P's 1.5 mm lead gives a ~2.3 deg lead
                        # angle, well under the ~5.7 deg friction angle, so the
                        # screw IS self-locking and MEC-02 holds. This setting is
                        # therefore a preference, not a necessity - switching to a
                        # timeout is safe if ACC-04 shows the motor running hot.
                        # Also: set the TB6600 to 1.0-1.4 A/phase, NOT 2.8 A.
                        # The motor has >10x the torque this lift needs, and with
                        # no stall detection that is a hazard, not a comfort.
                        # Lower current also cuts the heat this setting causes.
  pulse_us: 4           # TB6600 needs a wide pulse; 4 µs is safe. Do not drop to 1.
  dir_delay_us: 5       # TB6600 direction setup time.
  disable_delay_us: 0

# --------------------------------------------------------------------------
# Second GRBL channel — the HMI link
# --------------------------------------------------------------------------
# Key names uart1 and uart_channel1 verified on FluidNC v4.1.0 (2026-09-13).
#   The second channel keeps the USB serial port free as a debug console.
uart1:
  txd_pin: gpio.17      # → HMI GPIO 17 (RX)
  rxd_pin: gpio.16      # ← HMI GPIO 18 (TX)
  baud: 115200
  mode: 8N1

uart_channel1:
  uart_num: 1
  report_interval_ms: 100    # Auto status, but v4.1.0 only sends it ON CHANGE -
                             # an idle machine sends nothing. So the HMI also
                             # polls with ? every 100 ms; 500 ms silence = link lost.
  message_level: Info

# --------------------------------------------------------------------------
# Z axis — the lift
# --------------------------------------------------------------------------
axes:
  z:
    # ######################################################################
    # #  PROVISIONAL - from the manufacturer spec, NOT yet measured.       #
    # #                                                                    #
    # #  sauter Frae-slift FML-P: 1.5 mm travel per revolution.            #
    # #    1600 pulse/rev (1/8 ustep) / 1.5 mm = 1066.67 steps/mm          #
    # #                                                                    #
    # #  Better than the old 800, which assumed a 2 mm lead on a machine   #
    # #  that was never built. But a datasheet is not a measurement.       #
    # #                                                                    #
    # #  MEASURE ON THE ACTUAL LIFT before cutting anything:               #
    # #    dial indicator, known number of motor revolutions,              #
    # #    steps_per_mm = 1600 / (mm travelled per motor revolution)       #
    # #                                                                    #
    # #  Full-step resolution at 1.5 mm lead = 0.0075 mm, which BEATS      #
    # #  MOT-01's <=0.01 mm requirement.                                   #
    # #  See docs/MECHANICS-RevH.md                                        #
    # ######################################################################
    steps_per_mm: 1066.67

    max_rate_mm_per_min: 720        # 12 mm/s rapid (Q14). MOT-08 wants ≥10 mm/s.
    acceleration_mm_per_sec2: 100   # conservative (Q16)
    max_travel_mm: 65               # PROVISIONAL — set by the lift body (MEC-01
                                    # wants ≥75 mm). Confirm actual usable travel.
    soft_limits: true               # MOT-09. Commissioning-only — the operator
                                    # cannot widen this from the panel, by design.

    homing:
      cycle: 1
      positive_direction: false     # home DOWNWARD to the bottom switch.
                                    # Positive Z = bit rising (Q19), so the
                                    # display reads bit height above the table.
      mpos_mm: 0                    # bottom switch = machine zero (MOT-04)
      seek_mm_per_min: 600          # 10 mm/s fast find
      feed_mm_per_min: 60           # 1 mm/s slow confirm — this second, slow
                                    # approach is what delivers MOT-06 accuracy
      settle_ms: 250
      # ⚠ VERIFY the soft-limit envelope convention. FluidNC derives the range
      #   from mpos_mm, max_travel_mm and the homing direction, and the sign
      #   convention differs between homing positive and homing negative. We
      #   home negative and work positive, which is the less common orientation.
      #   Prove it with $J= moves at BOTH ends before trusting it.

    motor0:
      limit_neg_pin: gpio.33:pu     # bottom — home reference AND negative limit
      limit_pos_pin: gpio.25:pu     # top — bounds the bit-change rapid (MOT-05)
      hard_limits: true
      pulloff_mm: 2.0               # increase to ~3.0 if inductive sensors are
                                    # fitted — larger release hysteresis

      # NOTE ON POLARITY — this is not the usual CNC convention.
      # Switches are wired NORMALLY CLOSED for fail-safe:
      #   idle (not at limit) → contact closed → pin pulled to GND → LOW
      #   at limit            → contact opens  → pull-up → HIGH
      #   broken wire         → floats         → pull-up → HIGH = triggered ✓
      # So the asserted state is HIGH, i.e. active-high, i.e. NO ':low'.
      # A cut wire faults the machine rather than silently disabling the limit.
      # An inductive NPN NC sensor presents identically — same pin string,
      # no config change. See docs/SCHEMATIC-RevH.svg block E.

      stepstick:
        step_pin: gpio.26           # → TB6600 PUL−
        direction_pin: gpio.27      # → TB6600 DIR−
        disable_pin: gpio.14        # → TB6600 ENA−
        # ⚠ TB6600 common anode (PUL+/DIR+/ENA+) goes to +3.3 V, NOT +5 V.
        #   At 5 V the ESP32's logic high leaves 1.7 V across the input
        #   optocoupler — above its ~1.2 V LED drop — so it never fully turns
        #   off. Result: missed steps at rapid, which under DEV-01 is silent
        #   depth error. See docs/BOM.md block D.

# --------------------------------------------------------------------------
# Touch-off probe
# --------------------------------------------------------------------------
probe:
  pin: gpio.32:low:pu   # plate to GND, croc clip to the bit → LOW when touching
  check_mode_start: true # FLT-02 self-check. A probe reading shorted at cycle
                         # start refuses the cycle — no override (Q24). A shorted
                         # probe would set Z0 wherever the bit happens to be,
                         # giving a plausible-looking cut at the wrong depth.

# --------------------------------------------------------------------------
# Control inputs
# --------------------------------------------------------------------------
control:
  feed_hold_pin: gpio.21:low:pu   # STOP button, momentary NO to GND.
                                  # Deliberately on THIS board, not the HMI
                                  # expander: a native control pin acts with no
                                  # HMI involvement, so STOP halts motion even
                                  # if the S3 has crashed or the UART dropped.
                                  # NOT an E-stop — that is the mains mushroom.

  macro0_pin: gpio.13:low:pu      # Foot switch, momentary NO to GND.
                                  # ⚠ SEE firmware/README.md — the foot switch
                                  #   needs BOTH edges (hold to plunge, release
                                  #   to retract) and a macro pin may only fire
                                  #   on assert. Unresolved until verified.
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

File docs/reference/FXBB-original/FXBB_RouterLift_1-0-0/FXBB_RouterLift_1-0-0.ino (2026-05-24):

/* **********************************************************************
    RouterLift V1.0.0

    V1: Startversion

    (c)2021 Frohnix Bastelbude -> https://www.youtube.com/user/Frohnix

    Die kommerzielle Nutzung der Software ist ausdrücklich untersagt.


************************************************************************* */

#include <Preferences.h>
#include <Arduino.h>
#include <ESP32Encoder.h>
#include <U8g2lib.h>
#include <SPI.h>
#include <Wire.h>
# define PULSEPIN 19
# define DIRPIN   15
# define HANDRADPIN_A_MINUS 27
# define HANDRADPIN_B_MINUS 14
# define PIN_BUTTON_SET_ZERO 13
# define PIN_BUTTON_SET_SPEED 4
# define PIN_BUTTON_MAX 16
# define PIN_BUTTON_AUTOZERO 17
# define PIN_BUTTON_AUTOZERO_ENABLED 5
# define PIN_BUTTON_TOOLCHANGE 32


ESP32Encoder handRad;

// *********************************** SPI Display ****************************************
U8G2_SSD1306_128X64_NONAME_F_4W_SW_SPI oledSPI(U8G2_R0, /* clock=*/ 18, /* data=*/ 23, /* cs=*/ 33, /* dc=*/ 25, /* reset=*/ 26);
// *********************************** I2C Display ****************************************
U8G2_SSD1306_128X64_NONAME_F_HW_I2C oledIIC(U8G2_R0, /* reset=*/ U8X8_PIN_NONE, /* clock=*/ 22, /* data=*/ 21);

// ********************************** Prog-Vars ****************************

float         threadPitch = 1.5; // Steigung der Spindel in mm
float         heightSensorMm = 9.0; // Sensor löst diesen Wert über dem 0-Punkt aus (negative Werte möglich)

int64_t         motorStepsPerRev = 400; // Steps Einstellung des Motors
int64_t         motorRamp = 25; // An/Abfahrrampe - kleiner = schneller (25=Standard)
int64_t         tcZeroRamp = 120; // Rampe für Toolchange und setZero
int64_t         tmpRamp = 0; // Ladervariable
bool            dirChange = true; // Drehrichtung des Motors umkehren (true / false)
int64_t         stepTimeMicros = 30; // Signallänge an die Endstufe in Mikrosekunden für einen Step
int64_t         motorSpeedMin = 10000; // Delay zwischen den Steps für minimale Drehzahl (größer= langsamer)
int64_t         motorSpeedMax = 250; // Delay zwischen den Steps für maximale Drehzahl (kleiner=schneller)
int64_t         motorSpeedTcZero =1000;
int64_t         motorSpeedTemp=0;

int             handWheelSlow  = 1;   // Multiplikator für feine Bewegung (Handrad-Klick = Motorsteps)
int             handWheelFast  = 5;  // Multiplikator für grobe Bewegung
int             handWheelSlowOld  = 0;   // Temp-Speicher für Setup und Neuberechnung des Encoders
int             handWheelFastOld  = 0;  // Temp-Speicher für Setup und Neuberechnung des Encoders
bool            handWheelIsFast = false;
bool            targetSet=false;
int64_t         targetSetValue=0;
int64_t         targetSetCounter=0;



// AB HIER KEINE VARIABLEN VERÄNDERN
// **************************** Microtimer ***************************
int64_t         microSec = 0; // Haupttimer
int64_t         microSecTmpDoStep = 0; // Delaytemp für Stepperschritte
//  ********************************* Steppermotor ******************************
volatile bool   doStep = false; // Motor soll einen Step machen
bool            doingStep = false; // Motor Step läuft;
bool            stepDir = true; // Drehrichtung
bool            stepDirIni = true; // Initiale drehrichtung, dient zur Kontrolle ob Drehrichtung während des laufs geändert wird
bool            runOut = false; // wird true sobald die Drehrichtung während des Laufs geändert wird
bool            runOutTargetSet = false;
int64_t         stepPos = 0; // aktuelle Motorposition in realen Motorsteps
int64_t         stepTarget = 0; // ziel Motorposition in realen Steps;
int64_t         stepTargetOld = 0; // vorherige Motorposition (Handrad, falss ein klick in die andere Richtung)float
float           motorSpeed = 0; // altueller MotorDelay ;
bool            motorRun = false; // Motor Läuft
int64_t         motorRunTimer = 30000; // nach x mikrosekunden wird motorRun auf false gesetzt
int64_t         motorRunTimerTmp = 0; // Tempspeicher
int64_t         way = 0; // absolute Wegstrecke des Motors
int64_t         accSteps = 0; // misst die Beschleunigungsschritte während der Strecke
int64_t         decSteps = 0; // misst die Bremsschritte während der Strecke
bool            acceleration = false; //motor beschleunigt
bool            deceleration = false; //motor bremst
bool            reachMotorOut = false;

// *********************************** Handrad **********************************
float         handRadMultiplier = 1;// 0.25; // HandradSteps -> MotorSteps & Einstellungssteps (Anzeige *4)
bool          handRadMode = true; // Position über Handrad
int64_t       handRadValue = 0; // hier wird die vorherige Position von Handrad geladen, bevor Settings
int           handWheelFactor = 0; // hier werden die Slow/Fast Variablen reingeladen

// *********************************** Sonstiges *********************************
float         mmPerStep = 0; // Rechenfaktor für die Anzeige
int64_t       stepPosDiff = 0; // Verschiebefaktor in Steps für Nullpunkt
float         mmDisplay = 0; // Anzeigewert fürs Display (unbearbeitet)
float         mmDisplayOld = 0; // Temp-Variable um Änderung festzustellen;
int64_t       setupCounter = 0; // Verzögerungscounter für Setup
bool          setupESP = false; // Setup-Mode
bool          ignoreZero = false; // Zero funktion ignorieren, wenn aus Setup zurück
int           setupMenu = 0;
int           lastSetupMenu = 0;

bool          buttonSetZero = true;
bool          buttonSetSpeed = true;
bool          buttonMaxHeight = true;
bool          buttonAutoZero = true;
bool          buttonToolChange = true;
bool          findZero = true; // Längensensor angeschlossen
bool          doFindZero = false; // prozedur zum höhe finden starten
int           findZeroSpeed = 20;
bool          doneFindZero = false; // prozedur höhe finden beendet
bool          driveToZero=false;
bool          doToolChange = false; // prozedur zum Werkzeugwechsel starten
int           toolChangeSpeed = 30;
int64_t       encoderSetupOld = 0; // vorherige Encoderposition im Setup um Richtung zu bestimmen
int64_t       workSpaceMm = 50; // Arbeitsbereich der Spindel
bool          workSpaceActive = false; // Workspace ist Aktiv
bool          workSpaceOnStartup = false; // Workspace bei Power on einstellen
bool          firstStart = true; // für autoworkspace nach PowerOn
bool          resetWorkSpace = false; // Workspace soll neu gesetzt werden (Toolchange)
int64_t       spindlePosMax = -1; // Position des Endschalters
int64_t       spindlePosMin = -1; // Posotion des Endschalters + WorkSpace
bool          typeEndstopNO = true;
bool          typeAutozeroNO = false;
bool          typeWlsNO = true;
bool          endstopError = false;
int64_t       endstopCounter = 0;
float         speedFactor=0;
bool          autoZeroRunning=false;

Preferences preferences;

TaskHandle_t Task1; // Dualcore

hw_timer_t * timer = NULL;
portMUX_TYPE timerMux = portMUX_INITIALIZER_UNLOCKED;

void IRAM_ATTR onTimer() {
  portENTER_CRITICAL_ISR(&timerMux);
  doingStep = false;
  portEXIT_CRITICAL_ISR(&timerMux);
}

void setup() {
  if (typeEndstopNO == false) {
    buttonMaxHeight = false;
  }
  if (typeAutozeroNO == true) {
    buttonAutoZero = false;
  }
  Serial.begin(115200);

  timer = timerBegin(0, 80, true);
  timerAttachInterrupt(timer, &onTimer, true);
  timerAlarmWrite(timer, 100000, true);
  timerAlarmEnable(timer);

  preferences.begin("routerLift", false);  //Ordner routerLift anlegen & verwenden
  motorSpeedMax     = preferences.getLong64("motorSpeedMax", motorSpeedMax);
  motorRamp         = preferences.getLong64("motorRamp", motorRamp);
  motorStepsPerRev  = preferences.getLong64("motorStepsPR", motorStepsPerRev);
  dirChange         = preferences.getBool("dirChange", dirChange);
  threadPitch       = preferences.getFloat("threadPitch", threadPitch);
  heightSensorMm    = preferences.getFloat("heightSensorMm", heightSensorMm);
  handWheelSlow     = preferences.getInt("handWheelSlow", handWheelSlow);
  handWheelFast     = preferences.getInt("handWheelFast", handWheelFast);
  toolChangeSpeed   = preferences.getInt("toolChangeSpeed", toolChangeSpeed);
  findZeroSpeed     = preferences.getInt("findZeroSpeed", findZeroSpeed);
  workSpaceMm       = preferences.getLong64("workSpaceMm", workSpaceMm);
  workSpaceOnStartup = preferences.getBool("workSpaceOnSt", workSpaceOnStartup);
  typeAutozeroNO    = preferences.getBool("typeAutozeroNO", typeAutozeroNO);
  typeEndstopNO     = preferences.getBool("typeEndstopNO", typeEndstopNO);
  typeWlsNO         = preferences.getBool("typeWlsNO", typeWlsNO);



  pinMode(PULSEPIN, OUTPUT);
  pinMode(DIRPIN, OUTPUT);
  digitalWrite(PULSEPIN, HIGH);

  pinMode(PIN_BUTTON_SET_ZERO, INPUT_PULLUP);
  pinMode(PIN_BUTTON_SET_SPEED, INPUT_PULLUP);
  pinMode(PIN_BUTTON_MAX, INPUT_PULLUP);
  pinMode(PIN_BUTTON_AUTOZERO, INPUT_PULLUP);
  pinMode(PIN_BUTTON_AUTOZERO_ENABLED, INPUT_PULLUP);
  pinMode(PIN_BUTTON_TOOLCHANGE, INPUT_PULLUP);

  ESP32Encoder::useInternalWeakPullResistors = UP;
  //handRad.attachFullQuad(HANDRADPIN_A_MINUS, HANDRADPIN_B_MINUS);
  handRad.attachSingleEdge(HANDRADPIN_A_MINUS, HANDRADPIN_B_MINUS);
  handRad.clearCount();
  handRadMode = true;
  handWheelFactor = handWheelFast;
  handWheelIsFast = true;
  //workSpaceOnStartup=true;
  xTaskCreatePinnedToCore(
    Task1code, /* Function to implement the task */
    "Task1", /* Name of the task */
    10000,  /* Stack size in words */
    NULL,  /* Task input parameter */
    2,  /* Priority of the task */
    &Task1,  /* Task handle. */
    0); /* Core where the task should run */


}


void loop() {
  speedFactor=motorStepsPerRev/800;
  tcZeroRamp=motorRamp*2;
  mmPerStep = threadPitch / motorStepsPerRev;
  buttonMaxHeight = digitalRead(PIN_BUTTON_MAX);
  buttonAutoZero = digitalRead(PIN_BUTTON_AUTOZERO);
  buttonToolChange = digitalRead(PIN_BUTTON_TOOLCHANGE);
  buttonSetSpeed     = digitalRead(PIN_BUTTON_SET_SPEED);
  
  if (!buttonSetSpeed && !setupESP) {
      delay(30);
      while (!digitalRead(PIN_BUTTON_SET_SPEED)) {
        delay(1);
        targetSetCounter++;        
        if(targetSetCounter>1000){
          if(targetSet==false){
            targetSet=true;
            targetSetValue=stepPos;
          }else{
            targetSet=false;
          }
          break;
        }
      }
      while (!digitalRead(PIN_BUTTON_SET_SPEED)) {}
      delay(30);
      if(targetSetCounter<=1000){
        if (handWheelFactor == handWheelFast) {
          handWheelFactor = handWheelSlow;
          handRad.setCount(stepPos / handWheelSlow / handRadMultiplier);
          handWheelIsFast = false;
        } else {
          handWheelFactor = handWheelFast;
          handRad.setCount(stepPos / handWheelFast / handRadMultiplier);
          handWheelIsFast = true;
        }
      }
      targetSetCounter=0;
      
    }
    
  if (digitalRead(PIN_BUTTON_AUTOZERO_ENABLED)) {
    if (typeAutozeroNO == false) {
      findZero = true;
    } else {
      findZero = false;
    }
  } else {
    if (typeAutozeroNO == false) {
      findZero = false;
    } else {
      findZero = true;
    }
  }
  microSec = esp_timer_get_time();


  // ****************************************** Handradbedienung *********************
  if (handRadMode == true) {
    handRad.resumeCount();
  }
  if (endstopError) {
    handRad.pauseCount();
  }
  if (setupESP == false && runOut == false && doToolChange==false) {
    stepTargetOld = stepTarget;
    if (handRad.getCount() < stepTargetOld - 1 || handRad.getCount() > stepTargetOld + 1) {
      stepTarget = handRad.getCount() * handRadMultiplier * handWheelFactor;
      if(!driveToZero){
      if (stepTarget > stepPos + motorStepsPerRev) {
        stepTarget = stepPos + motorStepsPerRev;
        handRad.setCount(stepTarget / handRadMultiplier / handWheelFactor);
      }
      if (stepTarget < stepPos - motorStepsPerRev) {
        stepTarget = stepPos - motorStepsPerRev;
        handRad.setCount(stepTarget / handRadMultiplier / handWheelFactor);
      }
      }else{
        if(stepPos==stepTarget){
          driveToZero=false;
        }
      }
    }
  }

  if (stepTarget > spindlePosMax && workSpaceActive == true) {
    stepTarget = spindlePosMax;    
    handRad.setCount(spindlePosMax / handRadMultiplier / handWheelFactor);
  }

  if (stepTarget < spindlePosMin && workSpaceActive == true) {
    stepTarget = spindlePosMin;    
    handRad.setCount(spindlePosMin / handRadMultiplier / handWheelFactor);
  }
  if(targetSet==true){
    if(stepTarget>targetSetValue){
      stepTarget=targetSetValue;
      handRad.setCount(targetSetValue / handRadMultiplier / handWheelFactor);
    }
  }

  //*********************************************************
  //            Soll/Ist Position für Motor
  //*********************************************************
  if (motorRun == false) {
    stepDirIni = stepDir;
  }
  if (motorRun == false) {
    tmpRamp = motorRamp;
  }
  if ((doToolChange || doFindZero || ((!buttonMaxHeight && typeEndstopNO) || (buttonMaxHeight && !typeEndstopNO))) && !endstopError && !setupESP) {
    tmpRamp = tcZeroRamp;
  }

if (stepTarget != stepPos) {
    if(motorRun==false){
      motorSpeedTemp=motorSpeedMax;
      if(doToolChange){
        motorSpeedTemp=motorSpeedTcZero;
      }
    }
    if (doingStep == false) {
      if (stepTarget < stepPos) {
        if (dirChange == false) {
          stepDir = false;
        } else {
          stepDir = true;
        }
        doStep = true;
        stepPos--;
      }
      if (stepTarget > stepPos) {
        if (dirChange == false) {
          stepDir = true;
        } else {
          stepDir = false;
        }
        doStep = true;
        stepPos++;
      }
      if (motorRun == false) {
        stepDirIni = stepDir;
      }
      motorRun = true;

      reachMotorOut = false;
      motorRunTimerTmp = esp_timer_get_time();



      way = abs(stepTarget - stepPos);
      acceleration = true;

      if (way <= accSteps) {
        acceleration = false;
        deceleration = true;
      }

      if (acceleration == true && motorSpeed > motorSpeedTemp) {
        motorSpeed = 1000000 * tmpRamp / motorStepsPerRev / ((accSteps ) + 1) ;
        accSteps++;
        decSteps++;
      }
      if (deceleration == true && motorSpeed < motorSpeedMin) {
        motorSpeed = 1000000 * tmpRamp / motorStepsPerRev / ((decSteps ) + 1) ;
        decSteps--;
        if (way > decSteps) {
          acceleration = true;
          deceleration = false;
          accSteps = decSteps;
        }
      }
      if (motorSpeed < motorSpeedTemp) {
        motorSpeed = motorSpeedTemp;
      }
      if (motorSpeed > motorSpeedMin) {
        motorSpeed = motorSpeedMin;
      }



    }
  } else {
    if (esp_timer_get_time() > motorRunTimerTmp + motorRunTimer) {
      motorRun = false;
      runOut = false;
    }
    motorSpeed = motorSpeedMin;
    accSteps = 0;
    decSteps = 0;
    acceleration = false;
    deceleration = false;
    if (runOutTargetSet == true) {
      runOut = false;
      runOutTargetSet = false;
    }
  }





  // *************** MAX HÖHE ************************+
  if (((!buttonMaxHeight && typeEndstopNO) || (buttonMaxHeight && !typeEndstopNO)) && !endstopError && !setupESP) {
    resetWorkSpace = true;
    doFindZero = false;
    doneFindZero = false;
    doToolChange = false;
    targetSet=false;
    handRad.pauseCount();
    if (stepTarget > stepPos) {
      stepTarget = stepPos;
    }

    if (stepTarget > stepPos - 20) {
      handRad.setCount(handRad.getCount() - (handWheelFast/handWheelFactor));
      endstopCounter = endstopCounter + (handWheelFactor * handRadMultiplier);
      if (endstopCounter > (motorStepsPerRev * 4 / threadPitch)) { //  ************************************************* FEHLER
        endstopCounter = 0;
        endstopError = true;
        resetWorkSpace = false;
      }
    }
  } else if (!endstopError) {
    if (!doToolChange) {
      handRad.resumeCount();
    }
    if (resetWorkSpace == true) {
      spindlePosMax = stepPos;
      spindlePosMin = spindlePosMax - ((workSpaceMm * motorStepsPerRev) / threadPitch);
      workSpaceActive = true;
      resetWorkSpace = false;
      endstopCounter = 0;
      handRadMode = true;
      /*
      preferences.putBool("workSpaceAct", workSpaceActive);
      preferences.putLong64("spindlePosMin", spindlePosMin);
      preferences.putLong64("spindlePosMax", spindlePosMax);
      */
    }
  }
  // ************** TOOLCHANGE ************************
  if (doToolChange && !setupESP) { 
    targetSet=false;   
    workSpaceActive = false;
    handRadMode = false;
    handRad.pauseCount();
    if (stepTarget < stepPos) {
      stepTarget = stepPos;
    }
    motorSpeedTemp=motorSpeedMax;
    stepTarget=stepPos+(toolChangeSpeed*2);
    handRad.setCount((stepTarget / handRadMultiplier / handWheelFactor)); 
    
  }
  // ************** AUTOZERO **************************
  if (doFindZero && !setupESP) {
    autoZeroRunning=true;
    targetSet=false;
    handRad.pauseCount();
    if (stepTarget < stepPos) {
      stepTarget = stepPos;
    }

    
      motorSpeedTemp=motorSpeedMax;
      stepTarget=stepPos+(findZeroSpeed*2);
      handRad.setCount((stepTarget / handRadMultiplier / handWheelFactor)); 
      if (stepPos >= spindlePosMax - 10 && workSpaceActive == true) {
        doFindZero = false;
        doneFindZero = false;
      }
    
  }
  if(autoZeroRunning){
  if (((!buttonAutoZero && typeWlsNO == true) || (buttonAutoZero && typeWlsNO == false)) && !setupESP && findZero == true) {
    if (doFindZero) {
      doFindZero = false;
      doneFindZero = true;
    }
    handRad.pauseCount();
    if (stepTarget > stepPos) {
      stepTarget = stepPos;
    }

    if (stepTarget > stepPos - 1 ) {
      handRad.setCount(handRad.getCount() - 1);
    }
  } else {
    if (doneFindZero && motorRun == false && !setupESP) {
      doneFindZero = false;      
      stepPosDiff = stepPos - (round(heightSensorMm * float(motorStepsPerRev) / threadPitch));
      driveToZero=true;
      stepTarget=stepPosDiff;
      handWheelFactor = handWheelSlow;      
      handWheelIsFast = false;      
      handRad.setCount((stepTarget / handRadMultiplier / handWheelFactor));      
      autoZeroRunning=false;
    }
    if (((buttonMaxHeight && typeEndstopNO) || (!buttonMaxHeight && !typeEndstopNO)) && !endstopError && !doToolChange) {
      handRad.resumeCount();
    }
  }
  }

  //*********************************************************
  //                      DOSTEP
  //*********************************************************  
  if (doStep == true && doingStep == false) {
    doingStep = true;
    digitalWrite(DIRPIN, stepDir);
    digitalWrite(PULSEPIN, LOW);
    delayMicroseconds(stepTimeMicros);
    digitalWrite(PULSEPIN, HIGH);
    microSecTmpDoStep = esp_timer_get_time();
    doStep = false;
    timerAlarmWrite(timer, motorSpeed, true);
  }
  /*
    if (doStep == false && doingStep == true) {
    if (esp_timer_get_time() >= microSecTmpDoStep + motorSpeed) {
      doingStep = false;
      ticker=esp_timer_get_time() - microSecTmpDoStep + motorSpeed;
    }
    }
  */
  //*********************************************************

}

void Task1code( void * parameter) {
  //oledIIC.begin();
  oledSPI.begin();
  oledIIC.begin();
  for (;;) {
    mmDisplay = mmPerStep * (stepPos - stepPosDiff);
    mmDisplay = round(mmDisplay * 100);
    mmDisplay = mmDisplay / 100;

    buttonSetZero     = digitalRead(PIN_BUTTON_SET_ZERO);    
    if ((!buttonToolChange || (workSpaceOnStartup && firstStart)) && !doFindZero  && !endstopError) {
      delay(30);
      while (!digitalRead(PIN_BUTTON_TOOLCHANGE)) {}
      delay(30);
      if (!setupESP) {
        if (!doToolChange && !setupESP ) {
          doToolChange = true;
          preferences.putBool("workSpaceAct", false);
        } else {
          doToolChange = false;
        }
      } else {
        setupMenu--;
        if (setupMenu < 1) {
          setupMenu = 15;
        }

      }
    }
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

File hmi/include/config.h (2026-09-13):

#pragma once
//
// routerLift HMI — tunable constants.
//
// Every value here was decided in docs/DESIGN-QA.md; the Q number is cited so
// a reviewer can find the reasoning rather than guess at intent.
//
// Motion limits are NOT here. Soft limits, travel and steps_per_mm live in
// firmware/config.yaml and are commissioning values the operator cannot reach.
// This board never writes them.

#include <stdint.h>

// ------------------------------------------------------------------ Link
namespace LinkCfg {

constexpr uint32_t BAUD = 115200;

// No status report for this long => link considered lost: feed hold is sent
// and Z0 is invalidated. Five missed polls at 10 Hz.  (docs/UART-PROTOCOL.md §7.2)
constexpr uint32_t TIMEOUT_MS = 500;

// Poll '?' at this rate, always. FluidNC v4.1.0's report_interval_ms only
// reports on change, so an idle machine (e.g. sitting in Alarm) sends nothing
// and the link would read as lost. Bench-verified in Step B, 2026-09-13.
constexpr uint32_t POLL_MS = 100;

// One command in flight at a time. Deliberately more conservative than the
// character-counting flow control a file streamer uses: these are short
// interactive commands, so simplicity beats throughput.
constexpr uint8_t  TX_QUEUE_DEPTH = 8;
constexpr uint16_t LINE_BUFFER       = 96;

// Give up waiting for 'ok' and fault. Homing and probing legitimately take a
// long time, so this is generous.
constexpr uint32_t ACK_TIMEOUT_MS = 60000;

} // namespace LinkCfg


// ------------------------------------------------------------------- MPG
namespace MpgCfg {

constexpr uint16_t PULSES_PER_REV = 100;   // ZS80-5E100S

// FALSE for the 74LVC14 two-stage buffer (on 3.3 V), which is non-inverting.
// Not a 74HCT14: that needs a 5 V supply and would put 5 V into the S3.
// The legacy firmware used true because it assumed PC817 optocouplers.
// Wrong value = wheel counts backwards.  (docs/BOM.md block G)
constexpr bool SIGNALS_INVERTED = false;

// ELE-09: two positions, not the legacy three-band x1/x10/x100.
constexpr float STEP_FINE_MM  = 0.01f;   // 1 rev = 1 mm
constexpr float STEP_ROUGH_MM = 0.10f;   // 1 rev = 10 mm

// Jog feed rate sent with $J=. Fast enough to feel responsive, inside the
// 12 mm/s machine rapid.  (Q14)
constexpr uint16_t JOG_FEED_MM_MIN = 600;

// --- The three mandatory handwheel rules (docs/UART-PROTOCOL.md §5) ---

// 1. Coalesce detents over this window into one $J= command. One command per
//    detent would flood the link on a fast spin.
constexpr uint32_t COALESCE_MS = 30;

// 2. Never let queued jog distance exceed one screw revolution ahead of the
//    reported machine position. Adopted from FXBB (ino:282-289), and it
//    matters more here because our commands cross a UART hop.
constexpr float LOOKAHEAD_LIMIT_REV = 1.0f;
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

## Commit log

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2026-05-24 fix: use dirInverted() for Dir invert calibration row
    The Calibration > Motor "Dir invert" row was reading and toggling
    Motor.isEnabled() instead of the direction-inverted flag, so the UI
    showed the enable state and the toggle clobbered direction with the
    inverse of the enable state. Add a dirInverted() accessor on
    MotorControl and use it in both Display and Menu.
    [Display.cpp, Menu.cpp, MotorControl.h]
2026-05-24 fix: first clean compile of v1.0 firmware
    Five real build problems surfaced when actually running pio run for the
    first time (previous session had no registry access).
    - platformio.ini:
    - paulstoffregen/XPT2046_Touchscreen @ ^1.4 is not in the PIO registry;
    only an alpha SHA is. Switch to the upstream GitHub repo URL.
    - Pin platform = espressif32 @ 6.6.0. Newer 7.x/8.x ship ESP-IDF 5.x
    which removed the legacy RMT macros that FastAccelStepper 0.30.x
    depends on (StepperISR_esp32_rmt.cpp fails to compile).
    - include/config.h: rename namespace MPG -> MPGCfg so it stops colliding
    with class MPG in src/MPG.h.
    - src/MPG.cpp, src/RateSwitch.cpp: update ::MPG::CONST references to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
    [config.h]
2026-05-25 feat: NVS-persisted calibration via Settings module
    Until now only Presets and the brass-stamp offset survived a power
    cycle - everything tunable from Calibration (steps/rev, pitch, dir
    invert, max speed, accel, soft limits, relay startup delay) reset to
    Mech/Safety defaults on every boot.
    Add src/Settings.{h,cpp} with a global Config object that:
    - begin() opens NVS namespace "rl-cfg", reads each field with the
    matching Mech::DEFAULT_* / Safety::* as fallback, then pushes the
    result into Motor / Zero / RouterRelay.
    - scheduleSave() marks the data dirty.
    - update() flushes to NVS once the user has been idle for 2 s. The
    debounce keeps NVS writes off the hot path while the wheel is spu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
    [Menu.cpp, Settings.cpp, config.h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]
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2026-09-02 docs: add requirement specification RevG and as-built wiring diagram
    RTL-SPEC-001 Rev G (20 Jul 2026) formalises the requirements across
    MEC/MOT/ELE/FW/OPS/SAF/PWR/FLT/ENV/MNT/ACC, with the change log in
    Annex A and the as-built drive components in Annex B.
    Rev G closes the controller-platform open item with a split
    architecture: FluidNC on an ESP32 for motion, and a Guition
    JC4827W543C (ESP32-S3) touch HMI over UART. New ELE-11 gives the HMI
    no motion authority - its failure must not initiate, sustain, or
    block stopping of motion.
    Also adds Figure 2, the terminal-level wiring diagram introduced at
    Rev F, and ignores docs/*.zip (the 112 MB vendor display pack exceeds
    GitHub's file size lim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
2026-09-02 refactor: retire bespoke firmware to legacy/ for the RevG pivot
    RevG replaces the single-ESP32 design with a split architecture: stock
    FluidNC on an ESP32 for motion, and an ESP32-S3 touch panel as the operator
    HMI over UART. FluidNC does not run on the ESP32-S3, and the S3 board cannot
    carry the full machine pin budget, so one controller can no longer do both.
    Moves src/, include/ and platformio.ini to legacy/. The code is kept as a
    porting reference for menu structure, screen layout and the debounced NVS
    flush; it is not built, as the new root platformio.ini defines only an hmi
    environment. The original tree layout is preserved at tag v1.1.0-bespoke.
    legacy/README.md records where each m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
    [Display.cpp, Homing.cpp]
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2026-09-02 docs: mark pre-Rev H drawings as superseded
    Renames the two obsolete drawings with a superseded- prefix so nobody builds
    from them by opening the wrong file. SCHEMATIC.svg describes the pre-RevG
    single-ESP32 design; wiring_diagram.svg (and its PNG) describes RevG's
    display-only HMI.
    Adds SUPERSEDED.md explaining what each one shows and, for the wiring
    diagram, the five specific ways it is now wrong - MPG on FluidNC GPIO 34/35,
    TB6600 common anode at 5 V, ENA n/c, no STOP button, and the wrong display
    board. Each of those would cause a real fault if built.
    Updates the references in DESIGN-PLAN-RevH.md and SCHEMATIC-RevH.svg to the
    new paths, and ignores Office lock files.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
2026-09-02 feat: FluidNC machine definition with provisional steps_per_mm (Phase 2)
    The entire motion-side implementation, as one YAML file. No C++ is written
    for this board and none should be - homing, limits, probing and step
    generation stay FluidNC's problem, which is the point of the split.
    Carries every value settled in the Q&A: 12 mm/s rapid, 100 mm/s2 accel,
    homing seek/feed 600/60 mm/min, 1/8 microstepping, idle_ms 255 so the motor
    never de-energises, must_home true with no exceptions, 2500 ms spinup as the
    SAF-03 plunge gate, and probe check_mode_start so a shorted probe refuses the
    cycle.
    steps_per_mm is boxed off as a placeholder in the file itself, not a
    measurement. 800 assumes the 2 mm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
    [config.yaml]
2026-09-02 feat: HMI increment 1 - link, handwheel and buttons (Phase 4)
    First compiling build in this repository. RAM 6.8%, flash 11.6% of 4 MB.
    Link is the GRBL sender and the single chokepoint for anything this board
    says to the motion controller. It keeps one command in flight and waits for
    ok, while realtime bytes bypass the queue entirely - a feed hold must never
    sit behind a pending acknowledgement. Parses status reports, probe results,
    errors and alarms. A probe reporting :0 made no contact and is treated as a
    failed touch-off, so Z0 stays invalid rather than being set wherever the bit
    happened to be.
    Wheel implements the three mandatory handwheel rules: coalesce detents over a
    30 ms window,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
    [Buttons.cpp, Link.h, Wheel.cpp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]
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2026-09-02 feat: HMI increment 3 - Z0 validity and named presets (Phase 4)
    Builds. RAM 22.5%, flash 21.8% of 4 MB.
    Zero owns the two-touch probe sequence and Z0 validity. FluidNC has no
    concept of Z0, so this is the most safety-relevant logic in the HMI. The fast
    first touch only finds roughly where the surface is; the slow confirming
    touch is what delivers MOT-06's tolerance. Z0 references the table top per
    Q21, so depth is bit projection above the table and independent of stock
    thickness.
    Invalidation follows FW-09: link loss, alarm, bit-change entry, failed probe,
    and never-set at boot. Homing loss and E-stop arrive as an alarm and are
    covered by that.
    There is no override anywhere - not on the p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
    [main.cpp]
2026-09-02 docs: workshop survey checklist for the lift body
    One-trip checklist for identifying and measuring the router lift body. The
    screw lead is flagged as the critical measurement since it sets steps_per_mm,
    SCREW_LEAD_MM and therefore every depth figure in the design; two independent
    methods are given.
    Also captures the drive interface, which decides the coupling and motor mount
    - the only fabrication in the build - plus travel, self-locking behaviour,
    backlash, switch mounting, router nameplate for the contactor rating, and
    carriage mass.
    Closes out the last eight open questions in DESIGN-QA.md once answered.
    Claude-Session: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
2026-09-02 docs: select the lift body and design the drive (mechanics Rev A)
    Closes the critical path. The mechanics were the last thing resting on an
    invented number.
    Rejects the JoinTech SmartLift Digital after inspection: its drive is a nylon
    pinion on a ring gear rather than a lead screw, that gear is a documented
    failure point, the manufacturer is out of business so there are no spares,
    and the drive input is on the top face where a motor would sit on the work
    surface. The transferable lesson is recorded - a hand-cranked mechanism is
    designed around an operator who stops pushing when something binds, and a
    stepper does not.
    Selects the sauter Fraeslift FML-P. 1.5 mm per revolution gives 1066.67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
    [config.h, config.yaml]
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2026-09-04 docs: investigate full-size router lift alternatives to the FML-P
    Shortlists three Banggood/AliExpress lifts that take 88.9 mm and 107 mm
    router motors, as a fallback should a full-size router be required: the
    ENJOYWOOD Heavy Duty, the Wnew Heavy Duty (same JGC factory item) and
    the SpeTool P01002. All are JessEm Mast-R-Lift II derivatives.
    Two things move against the FML-P. Travel rises to 100-107 mm, which
    meets MEC-01 and removes the 65 mm conflict. But the drive-from-below
    interface becomes unverified: none is known to have a bearing-supported
    lower screw end, so motorising one means a belt drive under the plate
    and a belt in the backlash budget, a departure from the Rev A direct
    coupli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
2026-09-04 docs: compare the four lift bodies on quality, capability and fit
    Puts the sauter FML-P beside the Wnew, ENJOYWOOD and SpeTool on one
    page. Specification table, a quality ranking on what can be verified
    today, capability scored against MOT-01/02, MEC-01/02 and the Rev A
    drive-from-below decision, and a fit section.
    The fit section reframes the question: the router is not yet bought, so
    the lift and the router are one decision. The 88.9/107 mm carriages are
    sized for 120 V North-American fixed-base motors; on 230 V the realistic
    occupant is a 80 mm VFD spindle or a 65 mm trim router. So the choice is
    a 43 mm spindle motor on the FML-P versus an 80 mm VFD spindle on an
    import, not "small rout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
2026-09-11 docs: rewrite README for the RevH split architecture
    The README still described the v1.0.0 single-ESP32 design that 01511d2
    retired to legacy/ — ILI9488, FastAccelStepper, MCP23017 board IDs, and a
    `pio run` that flashed the lift. Anyone landing on the repo was told to
    build a firmware that is no longer built.
    Replaces it with the two-board design: stock FluidNC on a classic ESP32
    configured by firmware/config.yaml, and our ESP32-S3 LVGL panel in hmi/
    acting as a GRBL sender. States the no-motion-authority invariant, the
    real per-increment status, and the two provisional screw-lead values that
    make every depth figure unverified until steps_per_mm is measured.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
2026-09-11 docs: backfill changelog from 1.0.1 through the Rev H pivot
    The changelog stopped at 1.0.0 and missed everything since: the two
    bespoke-firmware releases, the tag marking the pre-pivot state, and the
    whole RevG/RevH split-architecture rewrite.
    Adds 1.0.1, 1.1.0 and 1.1.0-bespoke, then an Unreleased section covering
    the pivot — FluidNC config, UART protocol, HMI increments 1-3, the Rev H
    design set and the lift-body investigation — with the design changes that
    came with it (commissioning-only soft limits, rough/fine selector, no
    motion authority in the HMI) and the known issues, including the
    provisional steps_per_mm that leaves every depth figure unverified.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
2026-09-13 docs: correct motor current in the Rev H drawings to 1.0-1.4 A/phase
    Both drawings labelled the TB6600 "2.8 A/phase", the Annex B.5 figure
    chosen when the mechanics were unknown. BOM.md, MECHANICS-RevH.md and
    DESIGN-QA.md have since superseded it: the lift needs ~0.15 N.m and the
    57HS76 delivers ~2 N.m, so the driver is set to 1.0-1.4 A/phase to keep
    the margin at 5-7x rather than >10x. With no stall detection an oversized
    motor drives through an obstruction instead of stalling.
    The drawings are what someone reads while setting the DIP switches, so a
    stale current there is the most consequential place for it to be wrong.
    Also drops the figure from the ENA rationale note, which argues the m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
2026-09-13 fix: FluidNC spindle key is Relay, not relay_spindle
    FluidNC v4.1.0 ignored the relay_spindle section at boot, leaving the
    router output on GPIO 4 unconfigured. Verified on a bare WROOM-32:
    boot log now reports Relay Spindle Out:gpio.4 with no ERR lines.
    Claude-Session: https://claude.ai/code/session_017ucH8TBwhZPTLmqgxuG6sB
    [config.yaml]
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2026-09-13 fix(hmi): target the Guition JC4827W543C QSPI panel
    The board in hand is a Guition JC4827W543C (NV3041A over QSPI), not the
    Sunton ESP32-4827S043 RGB board Rev H recorded. The RGB firmware booted
    cleanly and showed nothing. Identified from the factory demo backup
    (guition.com, Arduino_ESP32QSPI) and the board silkscreen.
    - Display: Arduino_ESP32QSPI(45,47,21,48,40,39) + Arduino_NV3041A, IPS
    inversion; backlight GPIO 1
    - Touch: GT911 on SDA 8 / SCL 4, INT 3, RST 38; both axes flipped
    (measured: top-left tap read ~460,230 before, ~25,25 after)
    - I2C is now clear of GPIO 19/20, so the native-USB console survives
    - MPG moved to GPIO 6/7 on P3 (11/12 are TF-card lines, not exposed)
    - pins.h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
    [Buttons.cpp, Display.cpp, main.cpp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]
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2026-09-13 feat(hmi): give the MCP23017 its own I2C bus on GPIO 15/16
    The JC4827W543C's touch bus (GPIO 8/4) reaches no connector, so the
    expander cannot share it as Rev H planned. It now runs on I2C bus 1 on
    connector P3 (SDA 15 / SCL 16) at 100 kHz, since this bus leaves the
    board on a cable. Needs external 4.7 k pull-ups at the expander.
    Bench-verified 2026-09-13: both buses initialise (15/16 and 8/4), panel
    renders, USB console stays up; MCP not yet wired so reports not found.
    Also corrects stale framebuffer comments - the QSPI panel keeps its own
    pixels, so there is no framebuffer in RAM.
    Claude-Session: https://claude.ai/code/s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
    [Buttons.cpp, Display.cpp, pins.h]
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2026-09-13 chore: correct code and config comments to the verified design
    Comments only - no behaviour, key or value changes (config.yaml
    values verified identical to HEAD with comments stripped; both HMI
    envs build).
    - MPG shifter named as 74LVC14 on 3.3 V, not 74HCT14 (pins.h,
    config.h, Wheel.cpp)
    - pins.h: module is the XH-S3E N4R8
    - config.h: POLL_MS / TIMEOUT_MS describe polling as required
    - config.yaml: uart1 keys verified; report_interval_ms reports only on
    change, so the HMI polls
    - platformio.ini: board name, hmi-diag rationale, PSRAM note
    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
    [Wheel.cpp, config.h, config.yaml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]
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2026-09-13 feat(hardware): add kisch, a KiCad schematic writer
    Implement Task 1 of the kicad-schematics feature: kisch core library with full
    s-expression parsing, KiCad symbol library support, sheet generation, and
    project management. Includes comprehensive test suite and test fixture library.
    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
    [kisch.py]
2026-09-13 feat(hardware): generate the motion carrier schematic
    Adds the motion-carrier KiCad schematic (ESP32 devkit sockets, five
    input-conditioning channels, field terminals for STEP/DIR/ENABLE,
    HOME/TOP/PROBE/FOOT/DRV_ALM, STOP, and the panel LINK) generated from
    Python via kisch. ERC: 0 errors, 52 warnings, all lib_symbol_issues /
    footprint_link_issues from kicad-cli's headless (no global library
    table) environment - expected and accepted.
    Fixes a real kisch.py bug found while reviewing the exported PDF:
    KiCad renders a symbol property's stored "at" angle combined with the
    parent symbol's own rotation, not as an absolute page angle, and not
    by simple (parent + stored) % 360 addition either - ver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
    [conditioning.kicad_sch, motion-carrier.kicad_sch]
2026-09-13 fix(hardware): stop power-net labels overlapping neighbouring rows
    Round-1 review found the "verified clean" claim in the task-2 report was
    false: rendering the committed motion-carrier.pdf at high resolution
    showed a power symbol's Value text ("GND", "+5V", "+3V3") still colliding
    with an adjacent pin's own number (J1, J2, J5, J6, J7, BAT54S), and on J4
    a genuine glyph-level merge between "STEP"/"DIR"/"ENABLE" and "+3V3" - the
    same severity as the original bug.
    Root cause was the fixed (2.54, ±2.54) diagonal offset every symbol
    property used: fine for an isolated part, but on a 2.54mm-pitch connector
    with a power net on every other pin, half of it alone is a full row
    pitch, so it reliably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
    [conditioning.kicad_sch, motion-carrier.kicad_sch]
2026-09-13 feat(hardware): generate the panel carrier schematic
    Adds the panel-carrier KiCad schematic (74LVC14 MPG level shifter, MCP23017
    button expander, MX1.25 leads to the display board, screw terminals) built
    via kisch, per hardware/tools/motion_carrier.py's pattern. ERC: 0 errors, 77
    warnings, all lib_symbol_issues/footprint_link_issues from kicad-cli's
    headless (no global library table) environment - expected and accepted.
    Step 1 (list_pins.py) found two symbol/pin corrections the task brief didn't
    anticipate: 74LVC14 isn't in the stock library (used 74xx:74HC14 with Value
    overridden, as the brief allowed for), and Interface_Expansion:MCP23017_SO
    doesn't exist (used MCP23017x-x-SO) - whose I2C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
    [panel-carrier.kicad_sch]
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2026-09-13 fix(hardware): stop power-net arrows overlapping the plain pin below them
    Review round 1 found a Critical, widespread legibility failure on the
    low-voltage sheet: any box_symbol() row where a POWER_NET pin (GND/+5V) sits
    directly above a plain-net pin had the plain label's text overlapped by the
    power flag's own arrow/ground-symbol graphic, not just its Value text (already
    covered by PowerNetLegibilityTest). Mechanism: the power flag's shape is
    centred on its own row and reaches about half of box_symbol()'s 2.54mm row
    pitch either side of it; a plain label is justified against the *bottom* of
    its anchor (label()), so it grows upward, toward the row above. Both reaches
    meet almost exactly at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
    [low-voltage.kicad_sch]
2026-09-13 feat(hardware): cross-check schematic pins against the firmware
    check_pins.py exports the motion-carrier and panel-carrier netlists via
    kicad-cli and fails if any GPIO or MCP23017 line disagrees with
    firmware/config.yaml or hmi/include/pins.h. verify.sh chains tests,
    schematic generation, ERC, PDF export and the pin check into one gate.
    Discovered that kicad-cli's kicadsexpr netlist writes pinfunction as
    "<pin_name>_<pin_number>" (e.g. GPA0_21), not the bare pin name assumed
    in the plan - netlist() now strips that suffix before matching.
    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
    [check_pins.py]
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2026-09-14 fix(hardware): decouple power-flag spacing from field_gap; fix hidden arrow text
    Two related kisch.py legibility bugs from code review:
    - field_gap was doing double duty: it moved a placed part's own
    Reference/Value AND a power flag's Value-to-arrow distance. A part placed
    with a large field_gap for its own text (U2 on the panel carrier,
    field_gap=27.94; the large system.py boxes) dragged its GND/+3V3 flags
    24-28mm from their own arrow. Decoupled: field_gap now only moves the
    placed part's own text; a power flag always keeps the old, fixed STUB gap.
    - A power flag's Value text can render with its leading glyph hidden behind
    its own arrow/ground-symbol graphic. Root-caused to th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
    [kisch.py]
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2026-09-14 fix(hardware): correct the DOIT devkit's D13/GND header order
    DEVKIT_LEFT had D13 and GND swapped relative to the DOIT v1 30-pin
    silkscreen. Both motion_carrier.py and check_pins.py key off this same
    list, so nothing downstream needed to change - regenerating fixes the
    wiring and check_pins still reports 0 mismatches.
    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
    [devkit.py]
2026-09-14 fix(hardware): close check_pins blind spots on the link, P4 and MCP GPA7
    check_pins.py cross-checks the schematics against the firmware, but missed
    three things a real mistake could sail through undetected:
    - The two ends of the HMI<->motion UART link (motion-carrier J8 pins 1-3,
    panel-carrier J3 pins 1-3) were never checked against each other, only
    each against the firmware/HMI side separately - so a link cable swapped
    at one connector but not the other would pass. New check_link().
    - Panel-carrier J2 (P4)'s power pins (1=GND, 2=+3V3) weren't checked at
    all, only its two signal pins.
    - The MCP23017's spare GPA7 input wasn't checked for actually being
    unconnected.
    Also: config_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
    [check_pins.py]
2026-09-14 fix(hardware): set the 74LVC14's own Datasheet/Description
    The 74LVC14 is drawn using the stock 74xx:74HC14 symbol (74LVC14 isn't in
    KiCad's library) with its Value overridden - but its Datasheet and
    Description properties still described the HC part. Set both via kisch's
    new place(fields=...) override support on all 7 unit placements (6 gates +
    the power unit) so nothing on the sheet points a datasheet/BOM lookup at
    the wrong part.
    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
    [panel_carrier.py]
2026-09-14 fix(hardware): regenerate schematics, symbol library and PDFs
    Regenerated output of the preceding fix-wave commits (contactor topology,
    devkit pin order, field_gap/arrow-legibility fixes, 74LVC14 fields,
    zero-length wire removal). ERC clean (0 violations on all three projects)
    and check_pins reports 0 mismatches.
    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
    [conditioning.kicad_sch, low-voltage.kicad_sch, mains.kicad_sch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]
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2026-09-14 fix(hardware): put the fuse before the E-stop and switch L and N at the contactor
    Decided 2026-09-14: the mains order is RCD, fuse, E-stop, and the
    router contactor is 2-pole so the router is isolated whichever way
    round the supply is wired. The live net after the E-stop is renamed
    L_ESTOP. BOM block A, WIRING-RevH diagrams 1 and 5 and the spec now
    agree with the drawing; the key switch stays between the relay
    contact and coil A1.
    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
    [low-voltage.kicad_sch, mains.kicad_sch]
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2026-09-14 fix(hardware): move the motion carrier link header away from the antenna
    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
    [motion-carrier.kicad_pcb]
2026-09-14 feat(hardware): lay out and route the panel carrier PCB
    80 x 62 mm, M3 hole in each corner. Display leads J1/J2 on the left edge,
    J3/J4/J5 along the top, J6/J7 along the bottom, wire entries facing their
    edges. C1/C2 decoupling distances are asserted in build(). U1 pin 8 drops to
    B.Cu through a locked escape via so its trace no longer starves GND pin 7.
    pcbkit.place now copies DNP, Datasheet and Description from the netlist, so
    schematic parity is clean at all severities.
    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
    [panel-carrier.kicad_pcb]
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2026-09-14 fix(hardware): pin the Freerouting jar, fail board DRC on warnings, share rule constants
    - get_freerouting.sh checks for the requested version's jar, not any jar
    - gen_pcb.py uses the pinned version's jar (pcbkit.freerouting_jar) and exits with a
    clear message if it is missing; DRC runs with --severity-all
    - verify.sh runs board DRC with --severity-all --exit-code-violations
    - pcbkit: rule constants, rect_gap/bbox_mm/hole_rectangle helpers, BoardBuilder
    holes/stitch_avoid/text_boxes; gen_pcb reads stitch_avoid from the builder
    - tests: hole has no net, hole rectangle, rect_gap, pinned jar; the .kicad_pro test
    now really runs load/apply/save twice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
    [gen_pcb.py]
2026-09-14 fix(hardware): rectangular motion holes, shared link labels, regenerate boards
    - motion carrier: M3 holes (4,4) (93,4) (4,56.5) (93,56.5), 89 x 52.5 mm, asserted
    as a rectangle, >=4 mm from edges, clear of courtyards/text, >=10 mm from the
    antenna keep-out; pitch silkscreen; DRV_ALM block lifted 7.5 mm; J2 refdes moved
    below its tail
    - J8 and panel J3 labelled GND / LINK_TX / LINK_RX with a straight-through note;
    panel R1-R5 moved down 1 mm to make room
    - stitch-avoid is builder state on both boards
    - README: hole coordinates and pitch, Freerouting version override, what
    regeneration overwrites
    Claude-Session: http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
    [motion-carrier.kicad_pcb, panel-carrier.kicad_pcb]
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
